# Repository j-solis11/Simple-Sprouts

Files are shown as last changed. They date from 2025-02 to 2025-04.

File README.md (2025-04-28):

# Simple Sprouts - Smart Vertical Farming System



## Quick Start Guide

Simple Sprouts is an autonomous vertical farming system designed for compact urban environments like university campuses and restaurants.
The system integrates smart sensing, adaptive watering and lighting, and AI-based plant health monitoring to enable users to grow plants
Indoors with minimal intervention.

### Project Overview

- **Build Status**: Completed and functional (April 2025)
- **Core Components**: Raspberry Pi 5, Custom PCB, Dual-Tier irrigation, Grow lights, Peltier temperature module, NoIR cameras
- **Key Features**: Three operation modes (Manual, Scheduled, Adaptive), AI plant health monitoring, Web-based user interface
- **Project Team**: Boston University ECE Senior Design Team 26 (Spring 2025)

## Getting Started

### Prerequisites
- Raspberry Pi 5 with microSD card (16 GB+ recommended)
- 24V DC power supply (3A minimum)
- WiFi connection for Firebase access
- React Native Expo for mobile/web interface
- Plant material and growing medium

### Initial Setup
1. Connect the 24V power supply to the system
2. Fill the water tank to the marked level
3. Connect to WiFi and ensure Firebase connectivity
4. Open the web app following the installation instructions in the Software README
5. Initialize plant settings through the app interface
6. Add growing medium and plant material to the containers

### Current Hardware State

- PCB: Fully functional, successfully powering all components through MOSFET switching.
- Power: Stable across all voltage rails (24V input, 12V and 5V regulated buses).
- Irrigation: Pump and solenoid valves reliably operate under manual, scheduled, and adaptive modes.
- Sensing: Soil moisture, temperature/humidity, air quality, and water tank level sensors provide live data.
- Heating: Peltier module + fan assembly actively regulates internal enclosure temperature.
- Enclosure: Sturdy, functional, and water-safe with protective barriers installed.
- Dashboard/Control: Hardware successfully communicates sensor and actuator states via Firebase and web app.

## Critical Lessons Learned

### PCB Design and Assembly
- Footprint Accuracy: Double-check footprints for all parts, especially connectors and larger diodes.
- Part Availability: Use components from suppliers that support automated assembly.
- Clear Labeling: Label all terminal blocks and GPIO pinouts.
- Flyback Protection: Always include flyback diodes across inductive loads, even as a just-in-case.

### Power System
- Oversize Power Supplies: Choose power supplies with 25–50% more headroom.
- Separate High/Low Power Paths: Keep high-current and sensitive signal paths isolated.

### Mechanical Assembly
- Splash Protection: Physical separation between water and electronics is critical.
- Wire Management: Use cable sleeves and zip ties to prevent mechanical stress.

### Testing and Validation
- System-Level Testing: Validate subsystems individually before full integration.
- Sensor Calibration: Calibrate sensors in the actual environment.

### Documentation
- Maintain detailed wiring diagrams from the beginning.

## Known Issues & Gotchas
- Sensor Drift: Soil moisture sensors may drift over time and require recalibration.
- Minor Leakage Possible: Valves tend to leak after overuse. Not used enough usually to reach this stage.

## Recommendations for Future Improvements
- Integrated load sensing for real-time diagnostics.
- Upgrade water tank sensing to more reliable float sensors.
- Add battery backup or solar integration for off-grid use.
- Get better-fitted valve fittings to combat leakage. 

## Current State and Future Development

### Current Implementation
- Fully functional Manual, Scheduled, and Adaptive modes.
- Full web-based control and monitoring.
- NDVI-based plant health monitoring.
- Real-time sensor logging via Firebase.

### Potential Future Development
- Cost-reduction through lower-cost microcontrollers.
- Local AI model deployment to reduce cloud dependency.
- Enhanced environmental control, i.e., humidity and CO2 control
- Expansion to multiple-layered growth systems.
- Integrating multiple users in the same household

### Critical Information for Future Teams

1. **Power Distribution**
   - The system uses a 24V DC supply stepped down to 12V and 5V. Always check voltage levels before connecting new components.
   - The custom PCB has MOSFETs controlling high-current devices. Be cautious when modifying connections to prevent damage.

2. **Irrigation System**
   - Water tube connections at the solenoid valves are pressure-fit and may need occasional reseating.
   - The water pump is rated for 12V but operates efficiently at 9- 15V. The current PCB provides ~12V to the pump.
   - **IMPORTANT**: Always maintain physical separation between water and electronic components.

3. **Software Dependencies**
   - Firebase integration requires proper API keys. See the Software README for setup details.
   - The MoonDream Cloud API has a free tier that may limit daily queries for plant health analysis.
   - React Native Expo dependency versions are critical - see package.json for specific versions.

4. **Sensor Calibration**
   - Soil moisture sensors are factory calibrated but may need recalibration for different soil types.
   - Typical moisture readings: 400-600 (very dry), 600-900 (ideal range), 900+ (overly wet)
   - Temperature sensors have ±1°C tolerance - cross-reference with ambient sensors if precision is required.

5. **Camera Setup**
   - NoIR cameras must be positioned at specific angles for proper plant assessment. Use the 3D-printed mounts.
   - The NDVI analysis uses specific thresholds for plant health determination - see model.py for details.

## Repository Structure

- `/Hardware` - PCB design files, component specifications, and hardware documentation
- `/Software` - Control scripts, web application code, and software implementation details
- `/Assets` - Images, diagrams, and supplementary files
- `/Documentation` - User manual, test plans, and additional project documentation

## Original Team Members

- Jared Solis (jared11@bu.edu)
- Sourav Shib (shib0826@bu.edu)
- Arthur Hua (ahua102@bu.edu)
- Dilhara DeSilva (dilharad@bu.edu)
- Alex Muntean (munteana@bu.edu)

## Conclusion

Simple Sprouts is a fully functioning prototype that brings together embedded systems, smart sensing,
adaptive control, and sustainable agriculture. Moving forward, careful attention to hardware reliability,
documentation quality, and iterative improvements will allow future teams to scale, enhance, and adapt the
platform to even greater applications.

*Boston University Electrical & Computer Engineering*  
*EC 464 Senior Design - Spring 2025*

---

For detailed hardware specifications, see [Hardware README](Hardware/README_HARDWARE.md)  
For software setup and details, see [Software README](Software/readme.md)

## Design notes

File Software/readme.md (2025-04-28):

# Simple Sprouts - Software Documentation

## Software Overview

The Simple Sprouts software stack consists of several interconnected components that enable autonomous plant monitoring, automated environment control, and a user-friendly web interface. The system is primarily built around a Raspberry Pi 5 running Python scripts that interface with sensors and actuators, with data exchanged via Firebase to a React Native Expo web/mobile application.

## Software Architecture and Modules

---

### Mobile App Interface (React Native / Expo)

**Location:** `/React_App`

The mobile app provides a user interface for:
- Viewing real-time sensor data
- Switching   
- Managing manual watering and lighting schedules
- Switching between manual and adaptive modes
- Viewing historical trends in environmental parameters

**Main components:**
- `app/navigation/AppNavigator.js`: 
   - Allows navigation between different screens in the app
   - Configures Tab screen for transitions between Mode Info, Health Info, and Plant Info screens
- `app/services/firebaseServices.tsx`: 
   - Allows communication to Firebase to connect to modules on Raspberry Pi 5
- `app/screens/BasicStatus.tsx`: 
   - Opening screen for the UI 
   - Allows user to see the status of each plant level or reinitialize a new plant
- `app/screens/more_info/ModeInfo.tsx`: 
   - Allows the user to see information pertinent to each mode, i.e. time till next schedule for Scheduling Mode
   - Initializes mode switching
- `app/screens/more_info/HealthInfo.tsx`: 
   - Allows the user to view Plant Health Analysis, which shows LLM results to queries that highlight health
   - Communicates with LLM to allow the user to query the model directly
- `app/screens/more_info/PlantInfo.tsx`: 
   - Displays current and historical sensor information

**Technologies used:**
- React Native Expo 0.22.15
- Expo Go SDK 52

---

### Sensing Script (Python / Raspberry Pi)

**Location:** `/Sensing_Actuation_Code`

   The Sensing_code.py allows Simple Sprouts to continuously monitor soil moisture, air temperature, humidity, CO₂ levels, and water tank levels, uploading this data in real time to Firebase for live user monitoring and automation. The Actuation_code.py uses this sensor data along with flags set from the user app to control the watering system, grow lights, and heater, enabling fully autonomous plant care across Manual, Scheduled, and Adaptive modes. Together, they allow the system to respond to environmental changes, automate daily routines, and minimize manual intervention for indoor vertical farming. 

**Main components:**
- `Sensing_Actuation_Code/sensing_code.py`: 
   - Continuously reads environmental data from AHT20 (temperature/humidity), PCT2075 (temperature), and SGP30 (CO₂/TVOC) sensors over I2C
   - Sample soil moisture and soil temperature from two Adafruit Seesaw soil sensors with different I2C addresses (0x36 and 0x39)
   - Structures all sensor readings into a JSON dictionary with timestamps for organized database updates
   - Uploads the latest sensor data every 2 seconds to the /sensor_readings/latest node in Firebase Realtime Database

- `Sensing_Actuation_Code/Actuation_code.py`: 
   - Manages GPIO-controlled components (lights, valves, pump, heater) on the Raspberry Pi 5 using gpiod and gpiozero libraries
   - Reads control flags and schedules from the Firebase flags_test node to determine component actions and schedules in their respective modes
   - Toggles components on/off based on time-based scheduling or live soil moisture readings
   - Samples an ultrasonic sensor every 5 seconds to measure water tank level and updates the reading to the sensor readings node in Firebase
   - Controls heater based on real-time air temperature relative to a user-defined target temperature

**Technologies used:**
- Libraries Used
  - firebase-admin
  - adafruit-circuitpython-sgp30
  - adafruit-circuitpython-ahtx0
  - adafruit-circuitpython-pct2075
  - adafruit-circuitpython-seesaw
  - board
  - busio
  - json
  - time
  - gpiod
  - gpiozero
- Raspberry Pi 5
- Firebase Realtime Database
- Python3

Notes: 
- Sensing_code.py - Must be ran inside a Python virtual environment (venv) or conda env because Adafruit CircuitPython libraries are installed via pip. I2C must be enabled on the Raspberry Pi. I2C can be enabled using sudo raspi-config.
- Actuation_code.py - Must be ran outside any Python environment because access to /dev/gpiochip0 and GPIO requires special device permissions that the venv typically doesn't have
- You need to have libgpiod installed on the system (sudo apt install gpiod)
- The Firebase credentials file must be correctly set in the absolute path

---
## Model and Camera modules (Python / Raspberry Pi)

**Location:** `/Model_Code`

The camera and model code:
- Takes routine images of the plants
- Processes the images into NDVI images to aid in assessing plant health   
- Sends images up to firebase to be displayed on the web app
- Stores images locally to be passes to model
- Model assess plant health and qualifications to be planted within the planter box
- Model also gives recommendations and schedules on how to take care of plants

**Main components:**
- `Model_Code/Camera_noIR.py`: 
   - Captures plant images and generates NDVI analysis to then send to Firebase
- `Model_Code/image_retrival.py`: 
   - Analyzes plant health and responds to user queries

**Technologies used:**
- NoIR camera
- MoonDream cloud API
- Firebase API
- OpenCv

---

## Flowchart of Modules
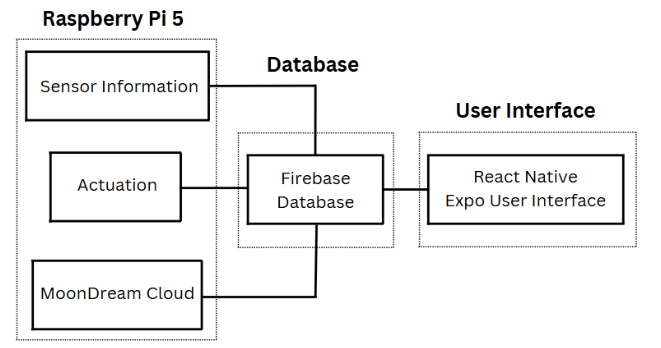
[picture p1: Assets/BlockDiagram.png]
Software Diagram


Here you can see the main flow of data in our logic. Firebase holds all of the hooks into the other modules, which allow the system to work with setting flags and exchanging data. All of the communication is designed with the UI either calling and recieving from the LLM or setting and receiving the sensor/actuation control.

## Software Dependencies and Versions

| Component | Version | Notes |
|---|---|---|
| Python | 3.11.2 | Core language for Raspberry Pi scripts |
| Firebase Admin SDK | 6.2.0 | Python library for Firebase integration |
| PiCamera2 | 0.3.25 | Camera interface library |
| OpenCV | 4.10.0.84 | Image processing library |
| Node.js | 18.16.0 | Required for React Native development |
| React Native | 0.22.15 | Mobile/web application framework |
| Expo Go | 52.0.0 | React Native development platform |
| MoonDream Cloud API | 1.0.0 | AI model API for plant analysis |
| firebase-admin | 2.7.0 | Interface with Firebase Database |
| adafruit-circuitpython-sgp30 | N/A | Air quality sensor interface  |
| adafruit-circuitpython-ahtx0 | 1.0.25 | Humidity sensor interface  |
| adafruit-circuitpython-pct2075 | N/A | Temperature sensor interface |
| adafruit-circuitpython-seesaw | 1.16.5 | Soil sensor interface |
| board | 1.0 | Adafruit Blinka Library |
| gpiod | 2.3.0 | Gpio Control |
| gpiozero | 2.0.2 | Gpio Control |

## Installation and Start up Guide

1. Clone the repository 
```bash
   git clone https://github.com/j-solis11/Simple-Sprouts.git
```
### Model
2. Create venv for camera and model code
```bash
python3 -m venv camera_and_model
source camera_and_model/bin/activate
```
3. Install dependencies for camera and model
```bash
pip install firebase-admin
pip install opencv-python
pip install pyrebase4
pip install requests
sudo apt install -y python3-picamera2
```
4. Activate camera and model code in 2 seperate terminals
```bash
python Camera_noIr.py
python image_retrival.py
```

### React App
2. Navigate to /Software/React_App/app/services/firebaseService.ts to put in Firebase API Key.

3. Open Command Prompt and navigate to /Software/React_App. 

4. Install Expo
```bash
npm install expo
```

5. Start app
```bash
npx expo start --tunnel
```
### Sensing and Actuation Code
2. Create the environment for the sensing script
```bash
python3 -m venv sensing_env
source sensing_env/bin/activate
```
3. Install dependencies for the sensing system
```bash
pip install firebase-admin adafruit-circuitpython-sgp30 adafruit-circuitpython-ahtx0 adafruit-circuitpython-pct2075 adafruit-circuitpython-seesaw adafruit-blinka
```
4. Enable I2C
```bash
sudo raspi-config
sudo reboot
```
5. Install dependencies for the actuation script
```bash
sudo apt install python3-pip python3-gpiozero libgpiod-dev python3-libgpiod
sudo pip3 install firebase-admin
```
6. Activate the environment for the sensing script
```bash
source sensing_env/bin/activate
python Sensing_code.py
```
7. Run the actuation script (In another terminal)
```bash
python3 Actuation_code.py
```

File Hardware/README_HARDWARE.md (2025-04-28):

# Simple Sprouts Hardware Report

## Overview

Simple Sprouts is an autonomous vertical farming system built around a custom-designed PCB, a Raspberry Pi 5
controller, and integrated environmental sensing and actuation. The system uses sensor feedback to manage irrigation, lighting, and temperature across a two-level enclosure. All design files, CAD models, schematics, and supporting documentation are included in the GitHub repository to allow future teams full access for reproduction or improvement.

This document serves as the complete hardware report, detailing schematics, PCB/CAD designs, Bill of Materials (BOM), datasheet references, power specifications, and physical system documentation.

## 1. Schematics, PCB, and CAD Diagrams

### Schematic Files:
- KiCad 8.0 project files (.sch) are located in /Hardware/KiCAD/Simple_Sprouts_PCB
- PDF exports of full schematic diagrams are provided for easy reference.

### PCB Layout Files:
- Full KiCad PCB layout files (.kicad_pcb) included.
- Gerber files for PCB fabrication provided in /Hardware/KiCAD/Simple_Sprouts_PCB/production
- PCB designed as a two-layer board with:
  - 2mm traces for high-current paths
  - 0.25mm traces for logic-level signals
  - Separate 12V and Ground planes
- 3D visualizations of PCB assembly available in /Hardware/Photos

### CAD Drawings:
- Mechanical design built primarily from plywood and 1/8" acrylic panels.
- Simple 2D CAD sketches (PDF) and final enclosure photographs provided in /Hardware/Photos

## 2. Vendor Information and Bill of Materials (BOM)

### PCB and Electrical Components:
- PCB Fabrication & Assembly: JLCPCB (www.jlcpcb.com)
- MOSFETs: Texas Instruments CSD18532Q5B
- Terminal Blocks: Phoenix Contact 1751248 (C89122)
- Flyback Diodes: SS510 Schottky Diodes (Microdiode)
- Soil Moisture Sensors: Capacitive 3.0–5.5V sensors (generic vendors)
- Temperature/Humidity Sensor: DHT22 (Adafruit)
- Air Quality Sensor: MQ-135 (Adafruit)
- Ultrasonic Distance Sensor: HC-SR04 (generic)
- Water Pump: 12V diaphragm pump (SparkFun equivalent)
- Solenoid Valves: 12V normally closed (Amazon)
- Grow Lights: 12V white LED strips
- Heating Unit: 12V Peltier Module + fan combo
- DC-DC Converters: 24V-12V and 24V-5V buck converters (Pololu)
- Power Supply: MeanWell GST60A24-P1J (24V, 2.5A output)

### Mechanical Components:
- 1/8" Acrylic Panels (Amazon)
- Plywood Sheets (Home Depot)
- Push-to-connect irrigation fittings
- 1/4" Tubing (Home Depot)
- M3 Screws and Nylon Standoffs

### Complete BOM:
- Located in /Hardware/Datasheets/SimpleSprouts_BOM.xlsx
- Includes quantity, part number, description, supplier link.

## 3. References to Datasheets and Design Resources
All are available in /Hardware/Datasheets
- MOSFET Datasheet: CSD18532Q5B
- Flyback Diode Datasheet: SS510 Schottky Diode Datasheet
- Phoenix Terminal Block Datasheet: 1751248 Datasheet
- Soil Moisture Sensor: Capacitive Sensor General Guide
- DHT22 Datasheet: DHT22 Humidity and Temperature Sensor
- Peltier Module Datasheet: TEC1-12706 (available in /Hardware/Datasheets/HardwareSensors/heater.pdf)
- MQ-135 Air Quality Sensor Datasheet: (available in /Hardware/Datasheets/HardwareSensors/air quality sensor.pdf)

## 4. Power Requirements

### Primary Power Source:
- 24V DC regulated supply rated at 3A (MeanWell GST60A24)

### Voltage Rails:
- 24V Primary Input Rail
- 12V Step-down Rail (via DC-DC converter) for:
  - Water Pump
  - Solenoid Valves
  - Peltier Heating Module
- 5V Step-down Rail (via DC-DC converter) for:
  - Raspberry Pi 5
  - LED Grow Lights
  - All environmental sensors

### Typical System Power Load:
- Raspberry Pi 5: ~1.5A @ 5V
- Water Pump: ~0.8A @ 12V (peak)
- Solenoid Valves: ~0.25A each @ 12V
- LED Grow Lights: ~0.5A total @ 12V
- Peltier Module + Fan: ~2A @ 12V (peak)

### Important Power Notes:
- Confirm 5V and 12V outputs before wiring critical loads.
- Avoid running pump and Peltier at full load simultaneously for long periods unless supply margin is verified.

## Power Requirements

| **Component** | **Voltage Requirement** | **Current Draw** | **Power Source** |
|:---|:---|:---|:---|
| Raspberry Pi 5 | 5V | 3A | 24-5V USB-C Converter |
| NoIR Camera Module (x2) | 5V | 125 mA (each) | 24-5V Converter |
| Water Cooled Water Pump | 12V | 300 mA | 24-12V Converter |
| Peltier Heating Module | 12V | 4A | 24-12V Converter |
| Solenoid Valve (x2) | 12V | 250 mA (each) | 24-12V Converter |
| Grow Light LED Strips (x2) | 5V | 3A (each) | 24-5V Converter |
| Soil Moisture Sensors (x2) | 5V | 10 mA (each) | 24-5V Converter |
| Temperature Sensor | 5V | 2.5 mA | 24-5V Converter |
| Humidity Sensor | 5V | 2.5 mA | 24-5V Converter |
| Air Quality Sensor | 5V | 2.5 mA | 24-5V Converter |
| Ultrasonic Distance Sensor | 5V | 15 mA | 24-5V Converter |

*Table: Summary of Power Requirements*

## 5. System Photographs and Assembly Documentation

Photographs have been captured and placed in /Hardware/Photos showing:
- PCB Top View (fully populated)
- PCB Side View (showing component height and header stacking)
- Full System Inside View (component wall and irrigation)
- Close-up of Irrigation System and Water Tank
- Cable Management and Tubing Routing
- Finished Enclosure with Plants Installed

### Notes on System Assembly:
- Maintain splash protection by securing acrylic barrier.
- Secure tubing with clamps and hot glue as needed.
- Run 24V input wiring separately from sensor wiring to avoid noise.
- Keep DC-DC converters in ventilated spaces inside the frame.

## 6. Additional Resources
- KiCad Project Backup (/Hardware/KiCAD/Simple_Sprouts_PCB/Simple_Sprouts_PCB-backups)
- Web links to component datasheets.

## Conclusion

The Simple Sprouts hardware platform is a fully operational and scalable embedded agricultural system.
With modular design choices, strong documentation, and open project files, it is positioned for
straightforward maintenance, upgrades, and future research use. By following careful engineering
practices, future teams can continue to enhance its sustainability, expandability, and
performance in smart agriculture applications.

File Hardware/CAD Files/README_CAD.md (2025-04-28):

This folder contains all of the CAD files we created to visualize our Simple Sprouts
project. Please note that these files are very outdated and were never kept up to date
because we felt that this was beyond our scope for the project and what we wanted to achieve.
We only wanted a simple frame that got the job done, we did not need to manufacture our own
custom parts with tolerances. Therefore, this folder serves as a visualization of the early stages
of Simple Sprouts, highlighting why we chose to go the way we did.

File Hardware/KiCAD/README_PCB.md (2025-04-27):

This is the PCB folder.
All necessary KiCAD files can be found within this folder.
In the "production" folder is the folder
used to export the schematics to JLC PCB for fabrication.

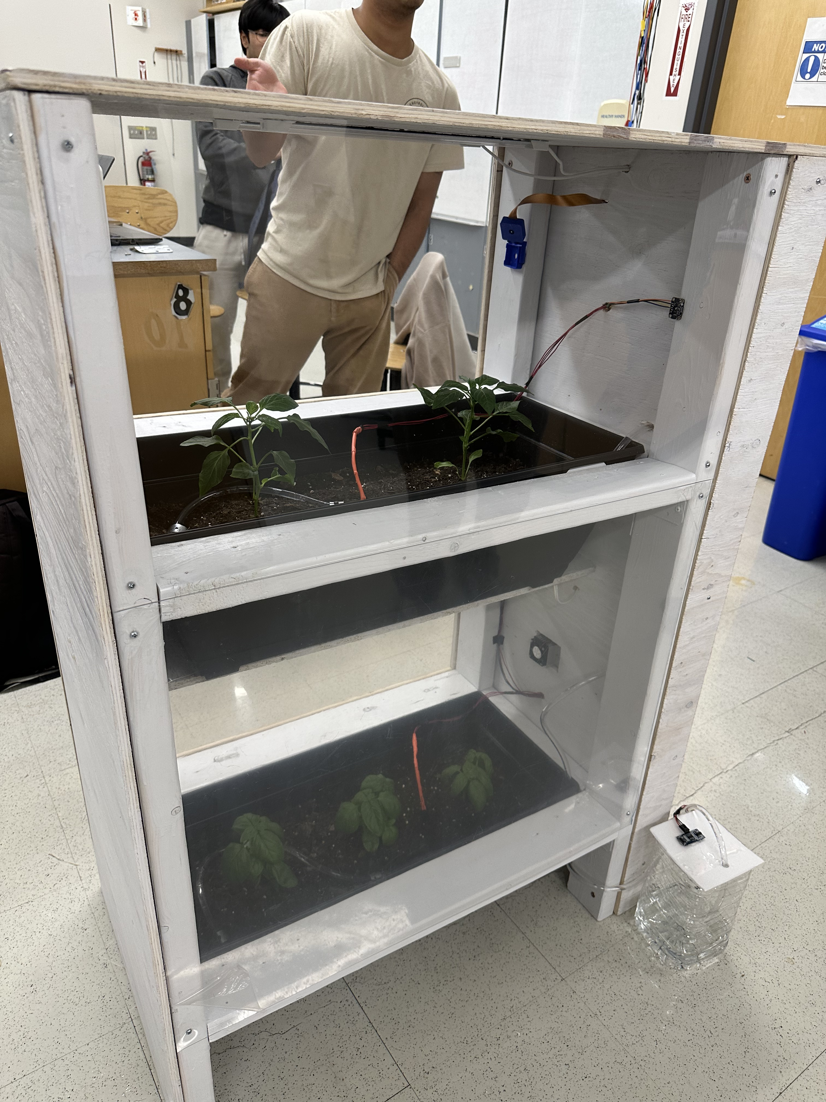
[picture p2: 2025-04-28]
Hardware/Photos/acyrlic.JPEG

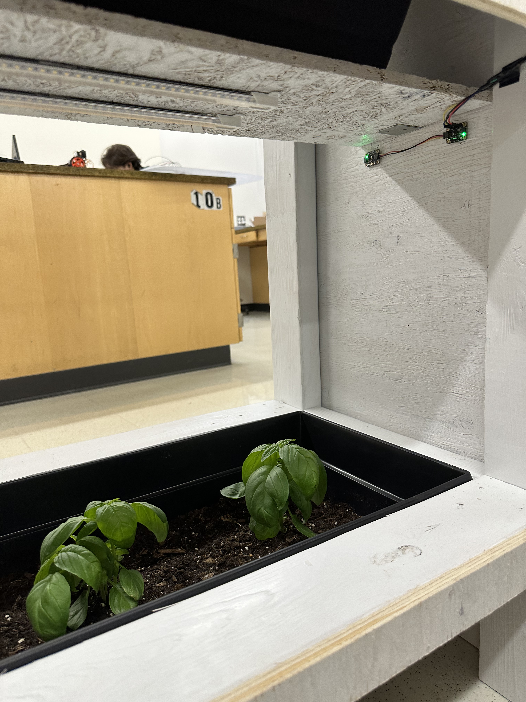
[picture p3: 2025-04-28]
Hardware/Photos/temp humidity sensors.JPEG

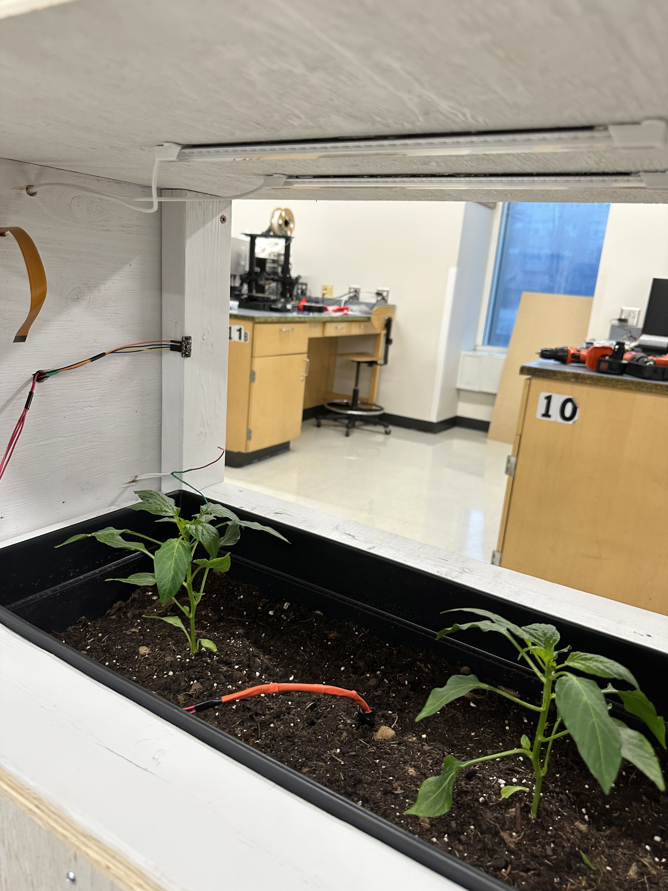
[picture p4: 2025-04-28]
Hardware/Photos/air quality sensor.JPEG

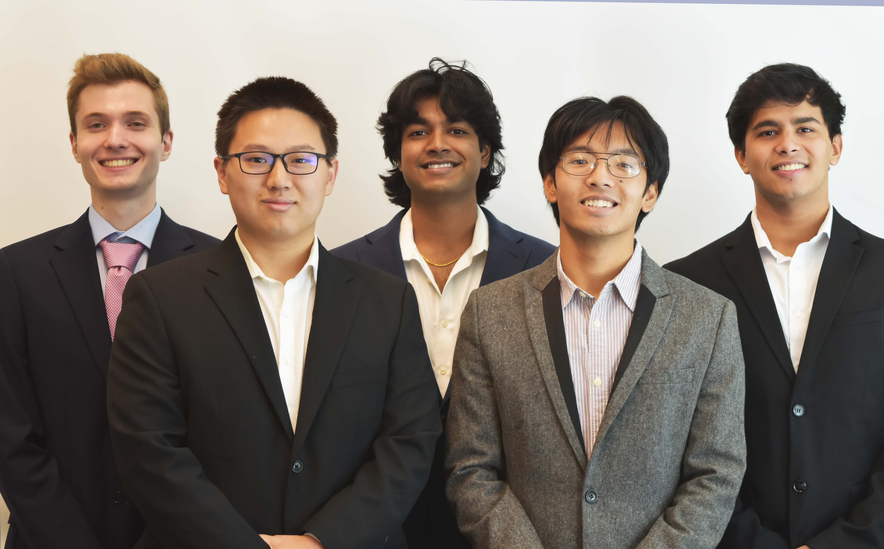
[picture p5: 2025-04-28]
Hardware/Photos/team photo.jpg

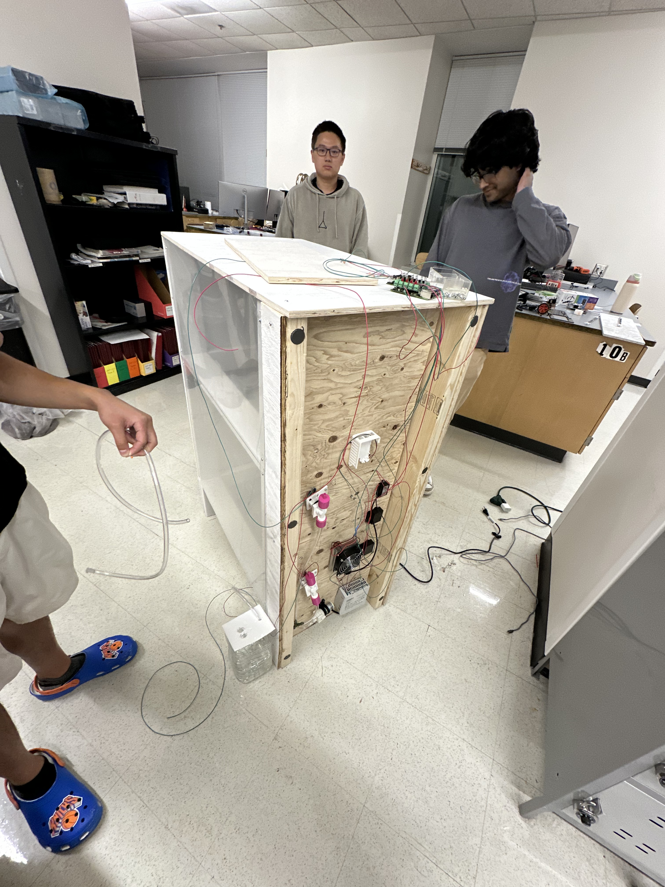
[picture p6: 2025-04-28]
Hardware/Photos/us working!.JPEG

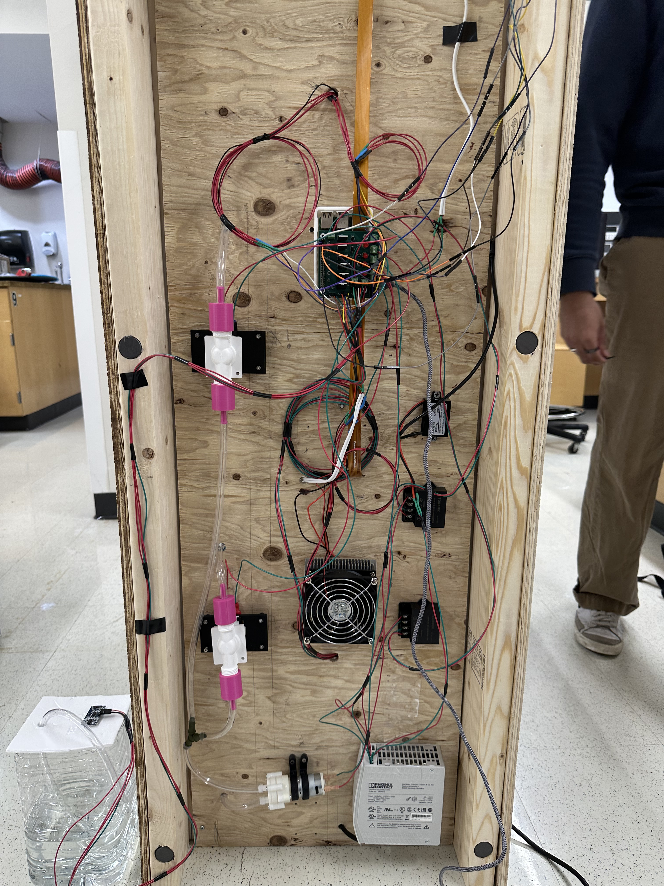
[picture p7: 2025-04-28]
Hardware/Photos/hardware panel.JPEG

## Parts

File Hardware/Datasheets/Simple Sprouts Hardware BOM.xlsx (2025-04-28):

Senior Design Expense Tracking
 | Vendor | Item(s) Purchased In Order | Total Cost
1) | Home depot | Black plant box | $24.98
2) | Home depot | Potting Mix | $9.97 | Total: | $740.52
3) | Home depot | Mini Marble Chips | $6.78
4) | Home depot | Clear Silicone Loctite | $6.28
5) | Home depot | PTFE tape | $0.98
6) | Home depot | Plastic lamp holder | $4.66
7) | Home depot | Pepper plants | $5.98
8) | Adafruit | Sensors and others | $92.55
9) | Amazon | jst cable | $8.00
10) | microcenter | Raspiberry pi 5 | $85.00
11) | amazon | noIR camera module | $29.99
12) | Adafruit | 2 x Plastic Water Solenoid Valve | $21.36
13) | Home Depot | zmax steel framing angle 1-1/2'' | $9.00
14) | Home Depot | zmax steel framing angle 3'' | $18.12
15) | Home Depot | plastic planter box | $6.32
16) | Home Depot | white wood planks | $23.10
17) | Target | Plant Germinating cups | $10.61
18) | Home Depot | Plant food | $11.97
19) | Home depot | Garden Soil | $4.57
20) | Newark | SCHOTTKY RECTIFIER, 5A, 100V | $11.80
21) | Mouser Electronics | Mosfet | $18.80
22) | Amazon | USB C Step Down Converter | $9.99
23) | Amazon | 120W Step Down Buck Converter | $9.39
24) | Amazon | Ribbon strip camera converter | $7.97
25) | Amazon | Grow light led strips | $27.98
26) | Amazon | New tube | $8.00
27) | Amazon | New pump | $10.00
28) | Amazon | DC 12v-24C step down | $11.00
29) | Digikey | PCB parts | $36.08
30) | Digikey | PCB (manufacturing) | $21.34
31) | Amazon | Acrylic | $32.29
32) | Amazon | noIR camera module | $32.99
33) | Amazon | Flexible camera cable | $7.97
34) | Home depot | zinc woodscrew 10@1.38 | $13.80
35) | Home depot | White spray paint 2@5.98 | $11.96
36) | Home depot | 1-1/2'' steel framing angle 10@0.90 | $9.00
37) | Home depot | plywood | $24.80
38) | Home depot | White spray paint 6@5.98 | $35.88
39) | Home depot | Steel framing angle 3'' 6@1.51 | $9.63
40) | Home depot | Steel framing angle 3'' 6@1.51 | $9.63

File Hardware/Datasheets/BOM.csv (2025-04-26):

Designator | Footprint | Quantity | Value | LCSC Part #
12V IN, 5V IN | TerminalBlock_Phoenix_PT-1,5-2-3.5-H_1x02_P3.50mm_Horizontal | 2 | Conn_01x02
D1, D2, D3, D4 | LED_D5.0mm | 4 | LED
D5, D6, D7, D8 | D_SMA | 4 | SS510
GROW1, GROW2 | TerminalBlock_Phoenix_PT-1,5-2-3.5-H_1x02_P3.50mm_Horizontal | 2 | ~
HEATER | TerminalBlock_Phoenix_PT-1,5-2-3.5-H_1x02_P3.50mm_Horizontal | 1 | R1
J1 | RPI Correct | 1 | Raspberry_Pi_5
J3, J4 | PinHeader_1x04_P2.54mm_Vertical | 2 | Soil Sensor
J6 | PinHeader_1x04_P2.54mm_Vertical | 1 | Temperature Sensor
J7 | PinHeader_1x04_P2.54mm_Vertical | 1 | Air Quality Sensor
J8 | PinHeader_1x04_P2.54mm_Vertical | 1 | Humidity Sensor
J9 | PinHeader_1x04_P2.54mm_Vertical | 1 | HC-SR04
Q1, Q2, Q3, Q4, Q5, Q6 | TO-220-3_Vertical | 6 | IRLB8721PbF
R10, R11, R12, R13, R14 | 1206 | 5 | 1kΩ
R15 | 1206 | 1 | 2kΩ
R2, R3 | 1206 | 2 | 4.7kΩ
R4, R5, R6, R7, R8, R9 | 1206 | 6 | 10kΩ
VALVE1, VALVE2 | TerminalBlock_Phoenix_PT-1,5-2-3.5-H_1x02_P3.50mm_Horizontal | 2 | L
WATER PUMP | TerminalBlock_Phoenix_PT-1,5-2-3.5-H_1x02_P3.50mm_Horizontal | 1 | 12V

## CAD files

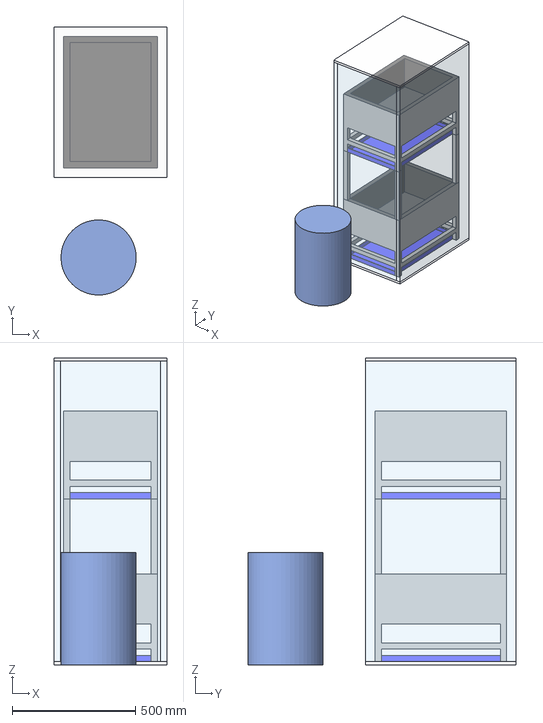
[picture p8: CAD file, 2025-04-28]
Hardware/CAD Files/Assembly 1.step
457.2 x 1087.4 x 1245.2 mm

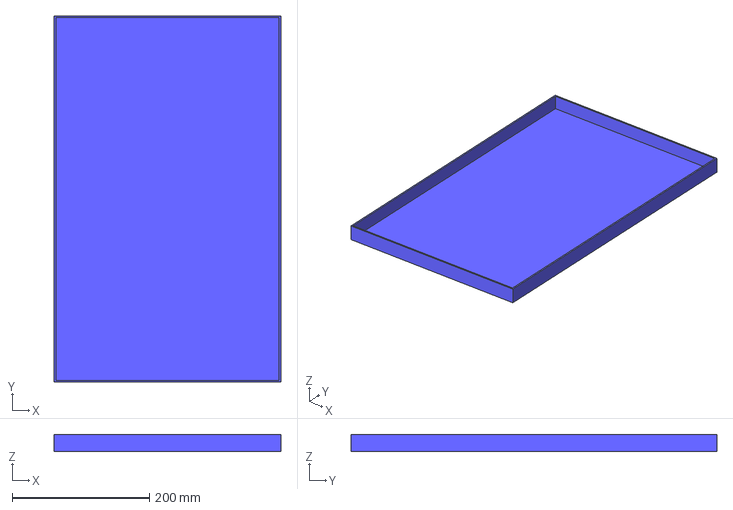
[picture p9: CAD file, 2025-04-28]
Hardware/CAD Files/Drip Tray.step
330.2 x 533.4 x 25.4 mm

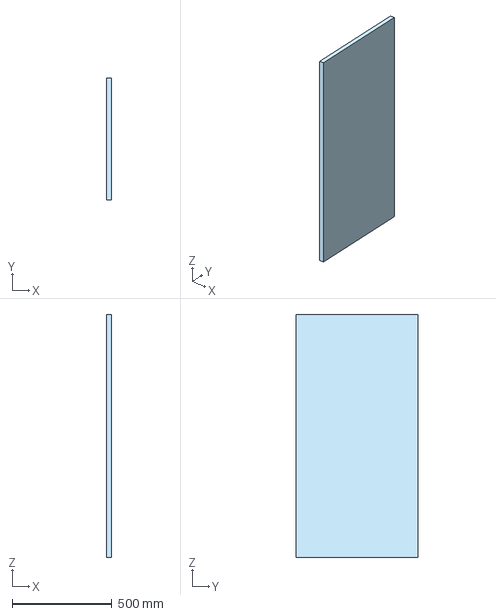
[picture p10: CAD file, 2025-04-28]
Hardware/CAD Files/Side Panels.step
25.4 x 609.6 x 1219.2 mm

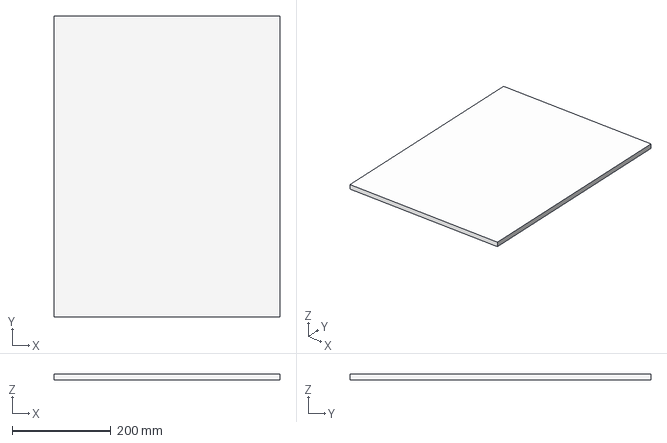
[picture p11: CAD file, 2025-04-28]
Hardware/CAD Files/Floor.step
457.2 x 609.6 x 12.7 mm

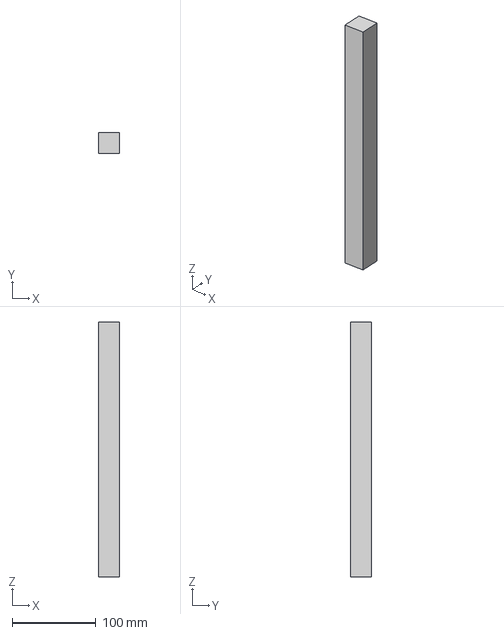
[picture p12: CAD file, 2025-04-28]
Hardware/CAD Files/Pillar Support.step
25.4 x 25.4 x 304.8 mm

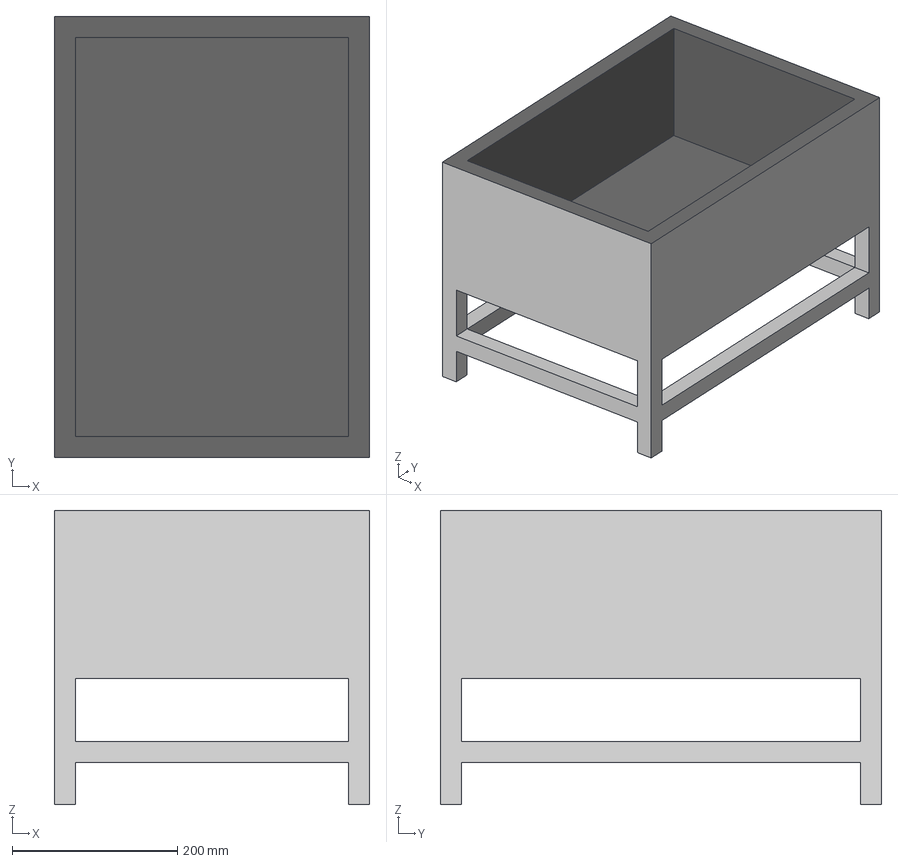
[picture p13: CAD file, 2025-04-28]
Hardware/CAD Files/Planter.step
381.0 x 533.4 x 355.6 mm

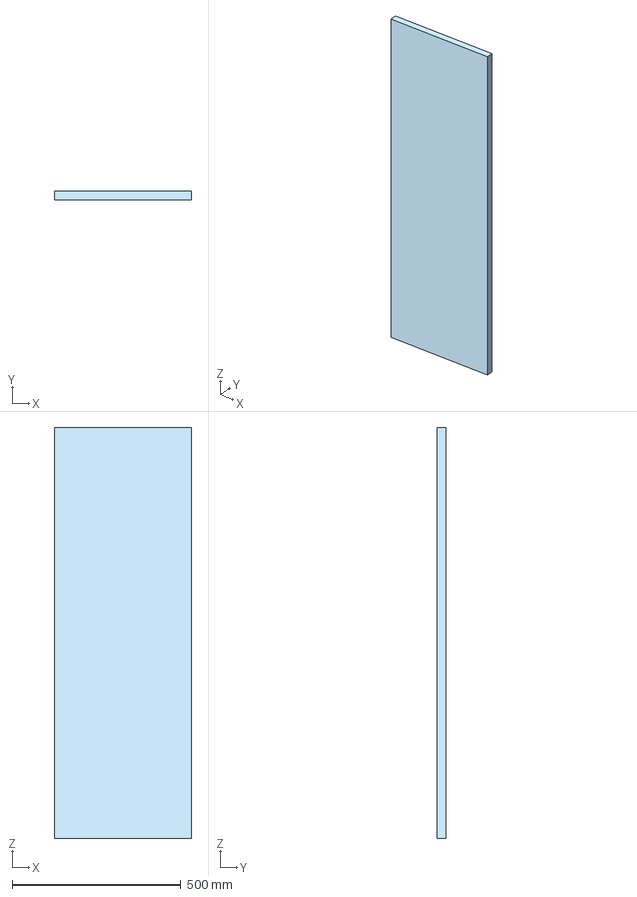
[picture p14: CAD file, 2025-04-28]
Hardware/CAD Files/Front & Back Panel.step
406.4 x 25.4 x 1219.2 mm

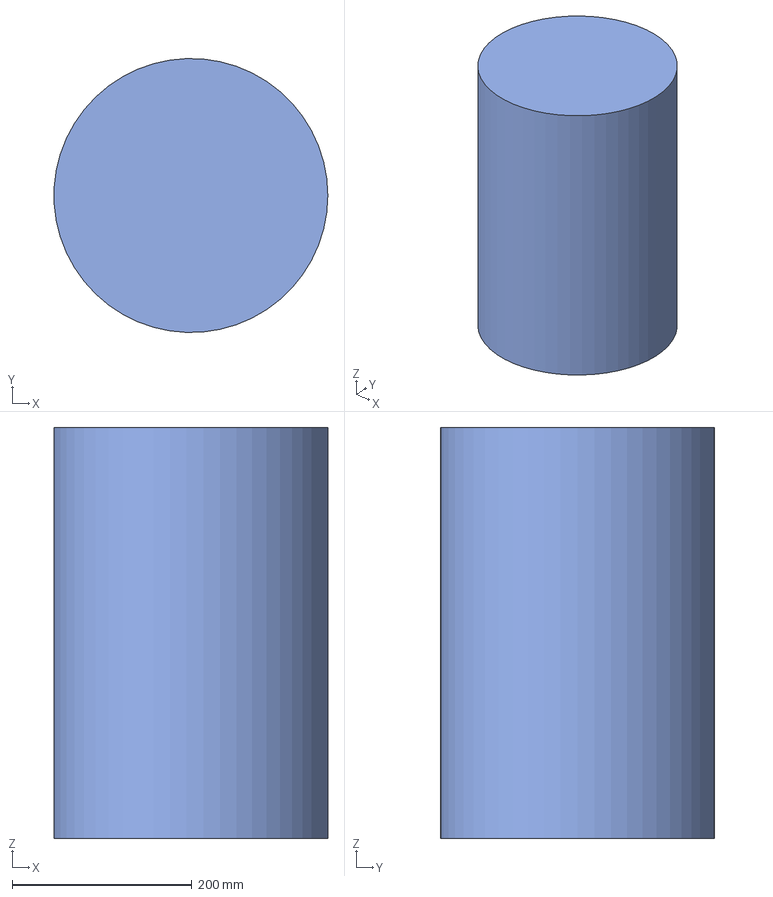
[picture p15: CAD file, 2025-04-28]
Hardware/CAD Files/Water Tank.step
304.5 x 304.7 x 457.2 mm

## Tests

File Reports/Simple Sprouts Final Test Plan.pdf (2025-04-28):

## Boston University Electrical & Computer Engineering

EC 464 Senior Design Project

## Final Product Testing Plan

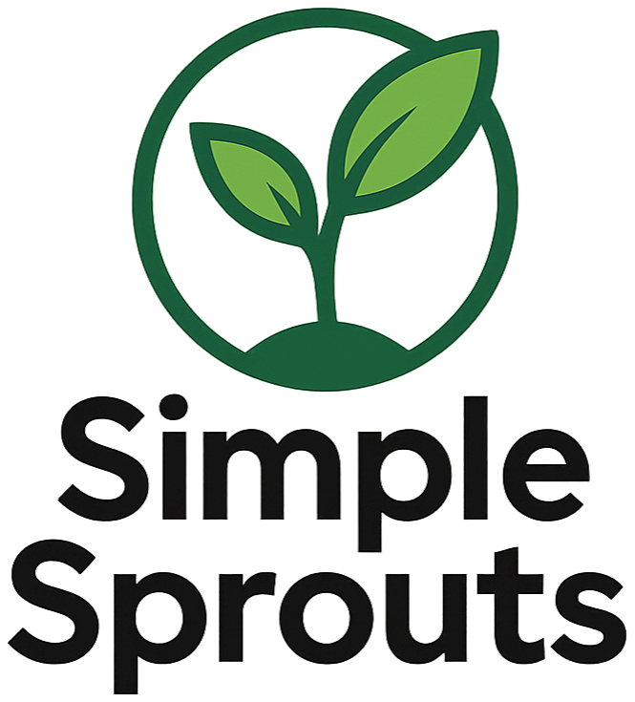
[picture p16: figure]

by
Team 26

Dilhara DeSilva dilharad@bu.edu Arthur Hua ahua102@bu.edu
Alex Muntean munteana@bu.edu Jared Solis jared11@bu.edu Sourav Shib shib0826@bu.edu

Required Materials

Hardware:
- Raspberry Pi 5
- 24V DC Power Supply
- 24V to 12V DC-DC Converter
- 24V to 5V DC-DC Converter
- 12V to 5V DC-USB-C Output Converter
- Raspberry NoIR Camera Module (2)
- 12V Water Cooled Water Pump Air Diaphragm Pump
- 12V Peltier Heating Module with Heat Sink and Fan
- 12V Solenoid Valves (2)
- Grow Light LED Strips (2)
- Soil Moisture Sensors (2)
- Temperature Sensor
- Humidity Sensor
- Air Quality Sensor
- Custom Fully Assembled PCB

Software:
- Python Scripts (Raspberry Pi GPIO control w/ scheduling logic, sensor handling)
- Capturing Photos & Object Recognition (OpenCV, TensorFlow for plant analysis)
- React Native Expo (Mobile/Web UI for monitoring and control)
- Node.js Web Server (Data visualization and API communication)
- Adafruit Sensor Libraries (for data collection from environmental sensors)
- Firebase (Cloud-based data storage and real-time updates for system communication)

Modes of Operation:

1. Manual Mode: User manually controls watering and lighting via the web app.
2. Schedule Mode: User sets their own or one of the predefined schedules for watering and lighting cycles.

### 3. Adaptive Mode: System responds dynamically based on sensor input and camera

feedback.

Set Up

The system consists of the following components:
- Raspberry Pi 5: Manages all sensor readings (soil moisture, temperature, humidity, air quality, water lever), controls the solenoid valves, water pump, and grow lights via GPIO-PCB control (using MOSFETs for on/off function), and processes infrared images for plant health monitoring. Handles requests with vision model for plant health
- Power Distribution: Uses a 24V DC power supply with three DC-DC converters (12V for the water pump, solenoids, and heater, 5V for the grow lights, and 5V USB-C for the Raspberry Pi).
- Web App: Displays real-time sensor data, images captured by the camera, and AI-based plant health assessments. Allows users to control and monitor the system remotely.
- Peltier Module: Maintains internal temperature within the optimal range for plant growth.
- Sweet Basil & Hot Banana Peppers: Test crops; the peppers were selected for their bright color to enhance camera-based plant health detection. Basil and other leafy greens like lettuce and spinach account for over 57% of crops grown in vertical farming systems.

All systems are now built on the custom PCB, replacing the individual breadboard circuits.

Pre-testing Setup Procedure

1. Connect all sensors (soil moisture, temperature, humidity, air quality, water level) to the Raspberry Pi and verify communication with RPI and Firebase
2. Ensure the Raspberry Pi is connected to the NoIR Cameras and can capture infrared images using Python. Ensure the Pi can process images using OpenCV and NVDI
3. Verify optimal water levels in storage manually.
4. Set up the DC power supply to provide 12V power for the water circuit and 5V for the Raspberry Pi and grow lights.
5. Ensure proper control of the water pump, solenoid valves, LED strips, and heater through the MOSFETs.
6. Upload and run the control code on the Raspberry Pi for automation and monitoring. Ensure timing for schedules is accurate
7. Run a test script to ensure image capture and AI-based plant monitoring functions correctly.
8. *Continuity Testing
a. Inspect PCB solder joints (MOSFETs, diodes) and water pump health (due to manufacturer’s notice).

Workflow Testing

1. Grow Light Activation
- Triggered via Raspberry Pi GPIO control through Schedule, Manual, or Adaptive mode.
2. Watering System
- Soil moisture sensor triggers water pump via Raspberry Pi in adaptive mode. In scheduling mode, the water pump and valves are triggered using timing schedules.
- Water pump and respective level is manually activated via Pi logic through the app.
- Water flows from the water pump to the Y-Connector and then through its respective solenoid valve.
i. Confirmed visually and through moisture sensor readings.
3. Camera & AI Processing
- Camera captures plant images with a NoIR and processes it to create an NDVI image to make assessing plant health easier
- Web app displays sensor data, IR plant images, and AI-based assessments.

### 4. Sensor Integration

- All environmental sensors upload real-time data to Firebase.
- Ultrasonic sensor detects and reports low water levels.
- Sensor script stores historical sensor data every twelve hours

### 5. Heater Module Test

- Activates automatically via Raspberry Pi Logic when enclosure temperature falls below 75℉ (± 5℉).
i. *Note For purposes of manual testing, this threshold can be set to a lower value in the code.

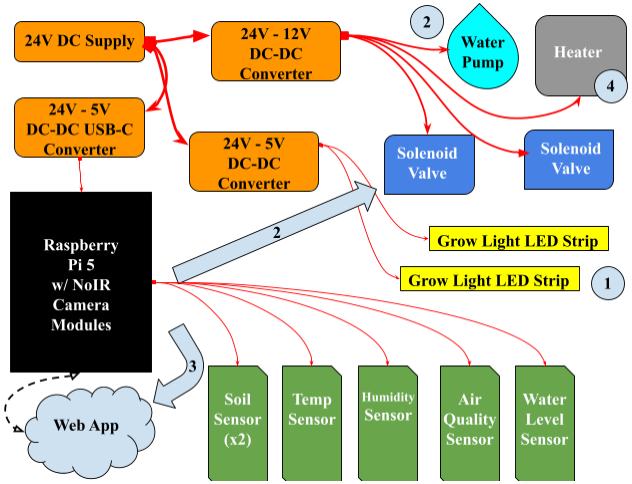
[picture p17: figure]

Figure 1: Illustration of Setup and Process Flow

Testing Procedure

Grow Light Test
- Confirm that the Raspberry Pi can toggle grow lights through both manual and scheduled modes via the web app.
- Ensure activation is time-aligned with defined schedule parameters.

Watering System & Soil Moisture Test
- Measure real-time soil moisture data from both sensors.
- Trigger watering cycle when soil moisture falls below a set threshold.
- Confirm pump activation and water flow through solenoid valves and Y-connector.
- Validate that the pump stops automatically once the desired moisture level is reached.
- Manually toggle watering ON/OFF from the app and verify the response.

Camera & AI Image Processing Test
- Capture images of Sweet Basil and Hot Banana Pepper plants using NoIR cameras.
- Uses MoonDream cloud API to evaluate plant health and get advice based on the images taken
- Confirm that captured images are correctly processed and health classifications are sent to the web dashboard through firebase.
Environmental Sensor Integration Test
- Collect real-time data from all sensors:
- Soil Moisture
- Temperature
- Humidity
- Air Quality
- Ultrasonic Distance Sensor (for water reservoir level)
- Ensure Raspberry Pi receives accurate readings and pushes updates to Firebase.
- Confirm data is correctly parsed and displayed on the web app interface with minimal lag or data loss.

Heating & Cooling System Test
- Test GPIO control of the heater module.
- Monitor temperature changes through the environment sensor before and after activation.
- Ensure thermal regulation maintains the desired enclosure range.

Measurable Criteria

Test Case | Expected Outcome | Pass/Fail
Grow Light Control A. Scheduled mode B. Manual mode C. Adaptive mode | Lights turn on/off as scheduled or in manual mode. Lights follow schedule set by model in adaptive mode
Water Pump Activation A. Scheduled mode B. Manual mode ————————— C. Adaptive mode | Water pump & its respective solenoid valve turns on/off as scheduled or in manual mode ———————————— Water pump & its respective solenoid valve turns on/off when the soil moisture sensor detects dry soil
Image Capture | Successful infrared image

| capture
AI Plant Assessment | Accurate AI evaluation of plant health
Sensor Data Display | Real-time data from temp/humidity/moisture/air/ul trasonic sensors is uploaded to web app and Firebase
Heating Functionality | Heating on/off toggles via Pi, confirmed by temperature changes

Additional Observations

- LED strips powered via PCB are brighter and more stable than in the breadboard prototype.
- System wiring is fully enclosed and neatly mounted.
- It is much more convenient with the PCB due to its terminal blocks for the systems’ wiring and the 4-pin connectors for the sensors’ wiring.
- Final hardware is now installed into a fully enclosed, multi-layer wooden frame with acrylic facing, allowing full view of the crops front and back.
- Ultrasonic sensor provides additional robustness by alerting users when the water tank needs refilling.
- Replacing SRDs improved overall power reliability and reduced noise during operation.

Future Steps (Pre-ECE Day)

- Make a permanent mounted enclosure for the water level sensor on the water tank.
- Re-apply paint to improve visual appeal.
- Laser engrave the team logo and name onto the side of the frame.
- Clean up wiring.
- Keep the system running to take care of our crops for ECE Day.

Conclusion

The Simple Sprouts project represents a fully integrated and functional automated plant care system, combining sensor feedback, intelligent control, and user interaction through a custom web interface. With the successful completion of the PCB build, full system soldering, and enclosure construction, the prototype now supports stable and efficient operation. New additions like the ultrasonic distance sensor and Peltier heating module enhance environmental control, while the grow lights, soil moisture sensors, and solenoid-pump irrigation system operate reliably through both scheduled and manual modes.
The inclusion of Sweet Basil and Hot Banana Peppers not only serves functional irrigation testing but also strengthens our AI model’s performance in real-time plant health monitoring through IR imaging. The bright coloration of the peppers improves contrast and detection accuracy for camera-based analysis. Cloud synchronization via Firebase enables seamless data flow between the Raspberry Pi and the web dashboard, maintaining live system transparency and control.
By completing the final hardware implementation, integrating all power, irrigation, and sensor systems into a unified architecture, Simple Sprouts is now positioned as a robust, scalable smart agriculture solution. Future directions will explore enhancing adaptive logic, expanding AI-based care recommendations, and refining mechanical features for long-term deployment.

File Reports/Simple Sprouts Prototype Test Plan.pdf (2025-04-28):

## Boston University Electrical & Computer Engineering

EC 463 Senior Design Project

## First Prototype Testing Plan

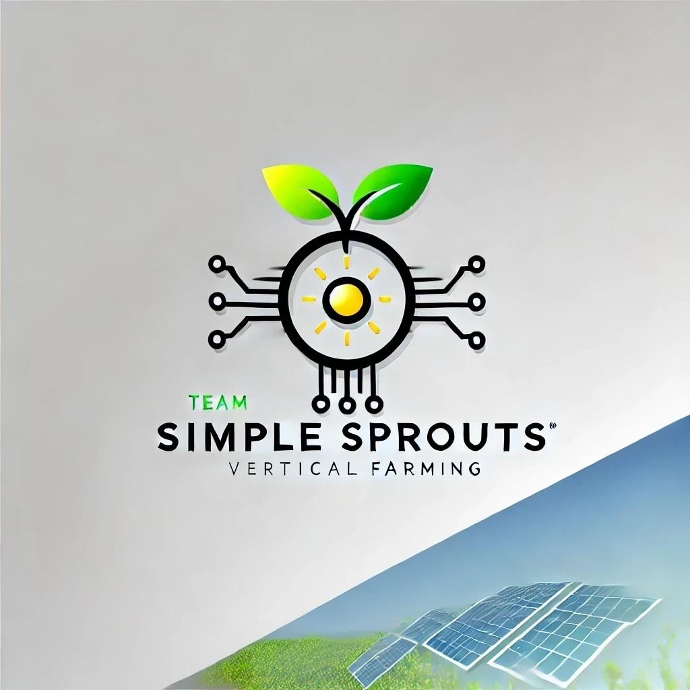
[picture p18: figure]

by
Team 26

Dilhara DeSilva dilharad@bu.edu Arthur Hua ahua102@bu.edu
Alex Muntean munteana@bu.edu Jared Solis jared11@bu.edu Sourav Shib shib0826@bu.edu

Required Materials:

Hardware:
- Raspberry Pi 1 Model B
- ESP32 Microcontroller
- 12V DC Variable Power Supply
- Camera Module (Logi Webcam HD 1080p)
- 12V Peristaltic Water Pump
- Adafruit Soil Moisture Sensors (2)
- SRD (2)
- 9V Battery
- 11W Grow Light
- Flywheel Diode
- Resistor
- Inverter

Software:
- Python 3 Scripts
- Capturing photos
- Object recognition
- Arduino IDE
- React Native Expo
- Arduino IDE for ESP32
- Python scripts for image recognition (OpenCV, TensorFlow)
- Web server (Node.js) for data visualization
- Sensor handling libraries (Adafruit libraries for sensors)

Set Up:

The system consists of the following components:

1. ESP32: Manages sensor readings (soil moisture, light, temperature, humidity) and controls the water pump and grow lights using step recovery diodes.
2. Raspberry Pi: Handles image capture using the webcam and processes the images using a trained model for ripeness detection.
3. Power Supply: Uses a DC variable power supply for consistent voltage output due to unreliable battery performance in previous tests.
4. Web App: Displays real-time sensor data and images captured by the camera.

Pre-testing Setup Procedure:

1. Connect all sensors (soil moisture, light, temperature/humidity) to the ESP32 and verify communication via I2C.
2. Ensure the Raspberry Pi is connected to the camera and can capture images using Python.
3. Verify optimal water levels in water storage.
4. Set up the DC power supply to provide 12V power for the water pump and grow LEDs.
5. Upload the control code to the ESP32 using Arduino IDE.
6. Run a test script on the Raspberry Pi to ensure image capture and basic object detection are functioning correctly.

Workflow Testing:
1. Light scheduled to turn on → ESP32 triggers grow light activation.
2. Soil moisture sensor detects dry soil → ESP32 triggers water pump activation.
a. Water pump scheduled to turn on → ESP32 triggers water pump activation.
3. Camera captures plant image → Raspberry Pi processes ripeness percentage through camera model → Web app displays all sensor data, the image, and ripeness status.

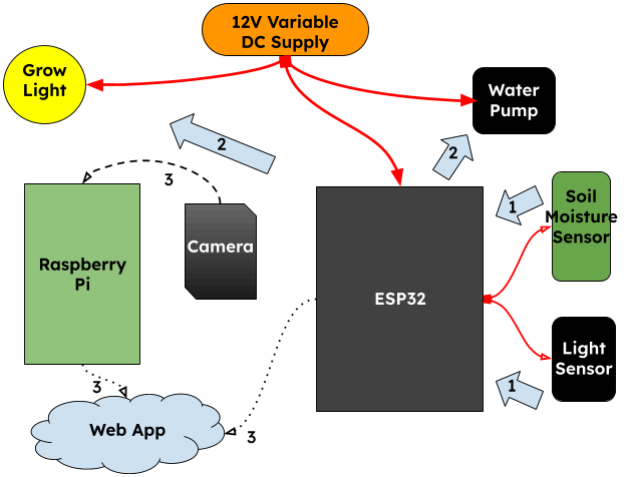
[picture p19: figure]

Figure 1: Illustration of Setup and Process Flow

Testing Procedure:

1. Lighting Test:
- Place the planter box under the grow lights.
- Use the light sensors to monitor ambient light levels measured in lux.
- Verify that the ESP32 adjusts the grow lights based on the sensor readings using the MOSFET control circuit.
2. Water Pump Test:
- Measure soil moisture levels using capacitive touch sensors. This system provides precise readings on a scale from approximately 200 (very dry) to 2000 (very wet), enabling accurate monitoring of soil hydration.
- Ensure the water pump operates correctly using the MOSFET control and stops once the desired moisture level is reached.
- The water pump operates from an ON/OFF command.
3. Camera and Image Processing Test:
- Set up the Raspberry Pi to capture images of the plants.
- Process the captured images using the Python script for ripeness detection.
- Display the processed image data and ripeness status on the web app.
4. Sensor Data Integration Test:
- Collect real-time data from all sensors (light [lux], soil moisture [200-2000], temperature [℉], humidity [%]).
- Verify that the ESP32 sends this data to the web app for visualization.
- Check the accuracy and stability of the displayed data.

Measurable Criteria:

I. The ESP32 should accurately control the grow lights based on light sensor data, maintaining optimal light levels for plant growth.

II. The water pump must activate when given the command to turn on from the ESP32.

III. The Raspberry Pi must successfully capture images and provide a ripeness assessment with an accuracy of at least 80%.

IV. The web app should display real-time sensor data (light, moisture, temperature, humidity) and image outputs without significant delay.

Score Sheet:

Test Case | Expected Outcome | Pass/Fail
Light Control | On/off function
Water Pump Activation | On/off function
Image Capture | Successful image capture
Ripeness Detection | Accurate ripeness assessment ( ≥ 80%)
Sensor Data Display | Real-time, accurate data on web app

Hardware Pinout

Component | ESP32 Pin # Raspberry Pi Pin # | Usage/Description
Soil Moisture Sensor | GPIO 34 | N/A | Moisture reading
— | GPIO 21 | N/A | Light level monitoring
— | GPIO 22 | N/A | Light level monitoring
Water Pump | GPIO 23 | N/A | Water pump control
Grow Lights | GPIO 24 | N/A | Grow lights control
Camera | N/A | USB | Image capture

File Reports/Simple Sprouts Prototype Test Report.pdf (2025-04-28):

## Boston University Electrical & Computer Engineering

EC 463 Senior Design Project

## First Prototype Report


by
Team 26

Dilhara DeSilva dilharad@bu.edu Arthur Hua ahua102@bu.edu
Alex Muntean munteana@bu.edu Jared Solis jared11@bu.edu Sourav Shib shib0826@bu.edu

Required Materials:

Hardware:
- ESP32 Microcontroller
- 12V DC Variable Power Supply
- Camera Module (Logi Webcam HD 1080p)
- 12V Peristaltic Water Pump
- Adafruit Soil Moisture Sensors (2)
- Temperature Sensor
- Humidity Sensor
- MOX Sensor (air quality)
- SRD (2)
- 9V Battery
- 11W Grow Light
- Inverter

Software:
- Python 3 Scripts
- Capturing photos
- Object recognition
- Arduino IDE
- React Native Expo
- Arduino IDE for ESP32
- Python scripts for image recognition (OpenCV, TensorFlow)
- Web server (Node.js) for data visualization
- Sensor handling libraries (Adafruit libraries for sensors)

Set Up:

The system consists of the following components:

1. ESP32: Manages sensor readings (soil moisture, temperature, humidity, MOX) and controls the water pump and grow lights using step recovery diodes.
2. Laptop: Handles image capture using the webcam and processes the images using a trained model for ripeness detection.
3. Power Supply: Uses a DC variable power supply for consistent voltage output due to unreliable battery performance in previous tests.
4. Web App: Displays scheduling information and all-time statistics (water, light).

Workflow Testing:
1. Light scheduled to turn on → ESP32 triggers grow light activation.
2. Soil moisture sensor detects dry soil → ESP32 triggers water pump activation.
a. Water pump scheduled to turn on → ESP32 triggers water pump activation.
3. Camera captures plant image → The laptop prompts the model → Model provides reasonable plant assessment → Web app displays scheduling information and all-time statistics.

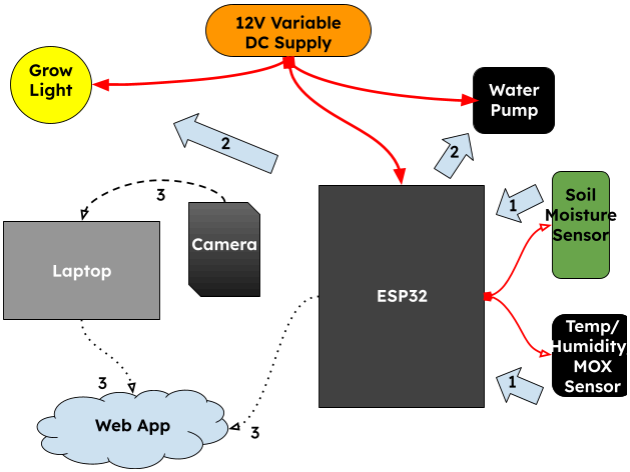
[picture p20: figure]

Figure 1: Illustration of Setup and Process Flow

Measurable Criteria:

I. The ESP32 should activate the grow lights when given the ON command, keeping light levels on and constant for plant growth.

II. The water pump must activate when given the command to turn on from the ESP32.

III. The camera and code script must successfully capture images and provide a reasonable plant assessment based on the image.

IV. The web app should display all-time information like total hours of light and total water deployed through scheduling without significant delay.

Score Sheet:

Test Case | Expected Outcome | Pass/Fail
Light Control | On/off function | ✓
Water Pump Activation | On/off function | ✓
Image Capture | Successful image capture | ✓
Plant Assessment | Plant type, plant health, ripeness | ✓
Sensor Data Display | Real-time, accurate data | ✓

Detailed Measurements:

Comprehensive testing was conducted to measure the performance of individual components and the overall system. The following measurements were recorded:

1. Soil Moisture Sensors:
- Sensor 1: Initial reading of 400 () before watering; post-watering, the reading increased to 1015, indicating optimal hydration.
- The sensor consistently provided accurate moisture levels, enabling reliable feedback for the water pump operation.
2. Temperature and Humidity Sensors:
- Temperature readings averaged 25°F, consistent with the controlled indoor environment.
- Humidity levels ranged between 20% and 40%, within the optimal range for the chosen plant type.
3. Air Quality Sensor (MOX):
- The MOX sensor measured CO₂ levels in ppm. During testing, CO₂ readings ranged from 350 ppm (ambient air quality) to 450 ppm, depending on environmental changes. These readings provide valuable data for understanding the growing environment.
4. Grow Lights:
- The grow lights were tested for simple on/off functionality. The lights activated reliably via the ESP32 command and remained operational for the desired duration. Total hours of light provided were tracked and displayed on the web app.
5. Water Pump:
- The water pump activated when manually triggered by the ESP32. It successfully delivered water until the soil moisture sensors indicated optimal levels. Total water dispensed was tracked and recorded on the web app.
6. Camera and Image Processing:
- Images captured by the camera were processed by the llama3.2vision model. Model responses included accurate identification of plant type, ripeness status, and health status, achieving an response time at approximately 4 minutes of processing per response.

Conclusions Based on Test Data:

The prototype testing revealed significant insights into the functionality and integration of the Simple Sprouts system. Key conclusions are as follows:

1. Grow Light and Water Pump Operation:
The ESP32 successfully controlled the on/off operation of both the grow lights and the water pump. While the grow lights and water pump performed reliably during manual testing, the lack of scheduling functionality highlighted an area for improvement. Scheduling automation is essential for reducing user intervention and improving the prototype's long-term reliability.
2. Sensor Data Integration:
The system seamlessly collected real-time data from all sensors, including soil moisture (2 sensors), temperature, humidity, and air quality (MOX sensor measuring CO₂ in ppm). These readings were accurately displayed on the web app, along with cumulative statistics such as total hours of grow light operation and total liters of water dispensed. The ability to monitor these metrics remotely demonstrates a critical step towards an autonomous vertical farming system.
3. Camera and Image Processing:
The camera model, integrated with chatbot functionality, provided accurate assessments of plant type, ripeness status, and health status. This feature adds significant value to the system by offering actionable insights to the user in an interactive format. While the reliance on a teammate's laptop for processing limits scalability, this temporary solution validated the potential of the image processing component.
4. Overall System Reliability:
The system proved reliable in its current state, with all sensors and actuators functioning as intended. However, addressing the lack of scheduling for the water pump and grow lights, as well as transitioning image processing to a dedicated onboard solution, are critical steps for the next iteration. These improvements will enhance autonomy and scalability for future deployments.

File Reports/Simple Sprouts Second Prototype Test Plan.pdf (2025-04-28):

## Boston University Electrical & Computer Engineering

EC 464 Senior Design Project

## Second Prototype Testing Plan


by
Team 26

Dilhara DeSilva dilharad@bu.edu Arthur Hua ahua102@bu.edu
Alex Muntean munteana@bu.edu Jared Solis jared11@bu.edu Sourav Shib shib0826@bu.edu

Required Materials

Hardware:
- Raspberry Pi 5
- 24V DC Power Supply
- 24V to 12V DC-DC Converter
- 12V to 5V DC-USB-C Output Converter
- Raspberry NoIR Camera Module
- 12V Peristaltic Water Pump
- 12V Solenoid Valves (2)
- Grow Light LED Strips (2)
- Soil Moisture Sensors (2)
- Temperature Sensor
- Humidity Sensor
- Air Quality Sensor
- 3 SRD Relays (Used to boost MOSFET current—one for the water pump, one for each LED strip)

Software:
- Python 3 Scripts (Raspberry Pi GPIO control, sensor handling, automation logic)
- Capturing Photos & Object Recognition (OpenCV, TensorFlow for plant analysis)
- React Native Expo (Mobile/Web UI for monitoring and control)
- Node.js Web Server (Data visualization and API communication)
- Adafruit Sensor Libraries (for data collection from environmental sensors)
- Firebase (Cloud-based data storage and real-time updates for system communication)

Modes of Operation:

1. Manual Mode: User manually controls watering and lighting via the web app.
2. Schedule Mode: User sets predefined schedules for watering and lighting cycles.

Set Up

The system consists of the following components:
- Raspberry Pi 5: Manages all sensor readings (soil moisture, temperature, humidity, and air quality), controls the water pump and grow lights via GPIO and SRD relays, and processes infrared images for plant health monitoring.

- Power Supply: Uses a 24V DC power supply with two DC-DC converters (12V for the water pump and solenoids, 5V for the Raspberry Pi).
- Web App: Displays real-time sensor data, images captured by the camera, and AI-based plant health assessments.
Note: The water level sensor is not used in this prototype due to wire length
limitations and the need for it to float.

Pre-testing Setup Procedure

1. Connect all sensors (soil moisture, temperature, humidity, air quality) to the Raspberry Pi and verify communication.
2. Ensure the Raspberry Pi is connected to the NoIR Camera and can capture infrared images using Python.
3. Verify optimal water levels in storage manually.
4. Set up the DC power supply to provide 12V power for the water circuit and 5V for the Raspberry Pi and grow lights.
5. Ensure proper relay control for the water pump and LED strips via the SRD relays.
6. Upload and run the control code on the Raspberry Pi for automation and monitoring.
7. Run a test script to ensure image capture and AI-based plant monitoring functions correctly.

Workflow Testing

1. Grow Light Activation → Raspberry Pi triggers grow lights via SRD relays based on the selected mode (Manual, or Schedule).
2. Watering System
- If soil moisture sensor detects dry soil → Raspberry Pi activates the water pump.
- The system alerts the user if water levels are low (manually checked in this prototype).
3. Camera & AI Processing
- Camera captures plant images in IR → Raspberry Pi processes plant health using AI.
- Web app displays sensor data, IR plant images, and AI-based assessments.

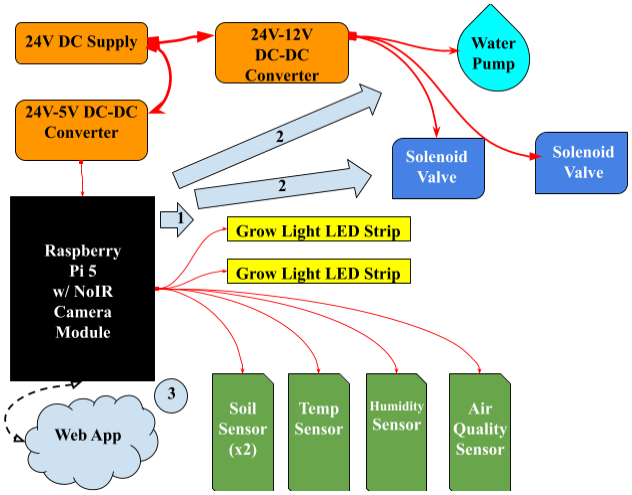
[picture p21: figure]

Figure 1: Illustration of Setup and Process Flow

Testing Procedure

Grow Light Test
- Verify that the Raspberry Pi triggers the grow lights via SRD relays according to the mode settings.
Water Pump & Soil Moisture Test
- Measure soil moisture levels using sensors.
- Ensure the water pump activates and stops at the desired moisture level.
- Validate the ON/OFF command functionality for the pump.
Camera & AI Image Processing Test
- Capture infrared images of the plants (lettuce, spinach, tomato) using the NoIR camera.
- Process captured images with AI to assess plant health and growth.
- Display real-time plant status on the web app.
Sensor Data Integration Test

- Collect real-time data from all sensors (soil moisture, temperature, humidity, air quality).
- Verify that the Raspberry Pi sends this data to Firebase and the web app.
- Check the accuracy and stability of displayed data.

Measurable Criteria

Test Case | Expected Outcome | Pass/Fail
Grow Light Control A. Scheduled mode B. Manual mode | Lights turn on/off as scheduled or in manual mode
Water Pump Activation A. Scheduled mode B. Manual mode | Pump activates at low moisture and stops when sufficient
Image Capture | Successful infrared image capture
AI Plant Assessment | Accurate AI evaluation of plant health
Sensor Data Display | Real-time, accurate data on web app and Firebase
Power Consumption | System operates efficiently

Future Plans & Notes

- Heater Implementation: The heater will be added in the final product but is not used in this prototype.
- PCB Integration: The second prototype does not use a custom PCB, but a PCB will be implemented in the final version for better efficiency and reliability.
- Historical Data Storage: The web app may store historical plant images and sensor data, but currently, only recent data is retained due to storage constraints.
- Improved GUI & AI Integration:
- The app will have a more intuitive interface.
- AI will provide recommendations for plant care based on image analysis.
- Sensor data visualization will be enhanced for better user experience.

Conclusion

The Simple Sprouts project integrates automated plant care with real-time monitoring, using Raspberry Pi-controlled sensors, relays, and AI-powered plant analysis. The system successfully incorporates manual and scheduled modes, providing flexibility based on plant needs. The cloud integration with Firebase allows seamless communication between components, ensuring efficient control and data storage.
The hardware implementation balances efficient power distribution, using a 24V DC supply stepped down to 12V and 5V for various components. The NoIR camera and AI model enhance the system by enabling plant health monitoring through infrared imaging, providing valuable insights into chlorophyll content and overall plant well-being.
While this prototype has validated key functionalities, future iterations will include a heater, PCB integration, and improved AI recommendations for plant care. With real-time data processing, image analysis, and an intuitive web-based control system, Simple Sprouts is a scalable solution for automated indoor gardening, offering a blend of technology and agriculture for sustainable growth.

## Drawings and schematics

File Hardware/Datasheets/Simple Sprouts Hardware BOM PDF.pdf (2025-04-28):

### Senior Design Expense Tracking

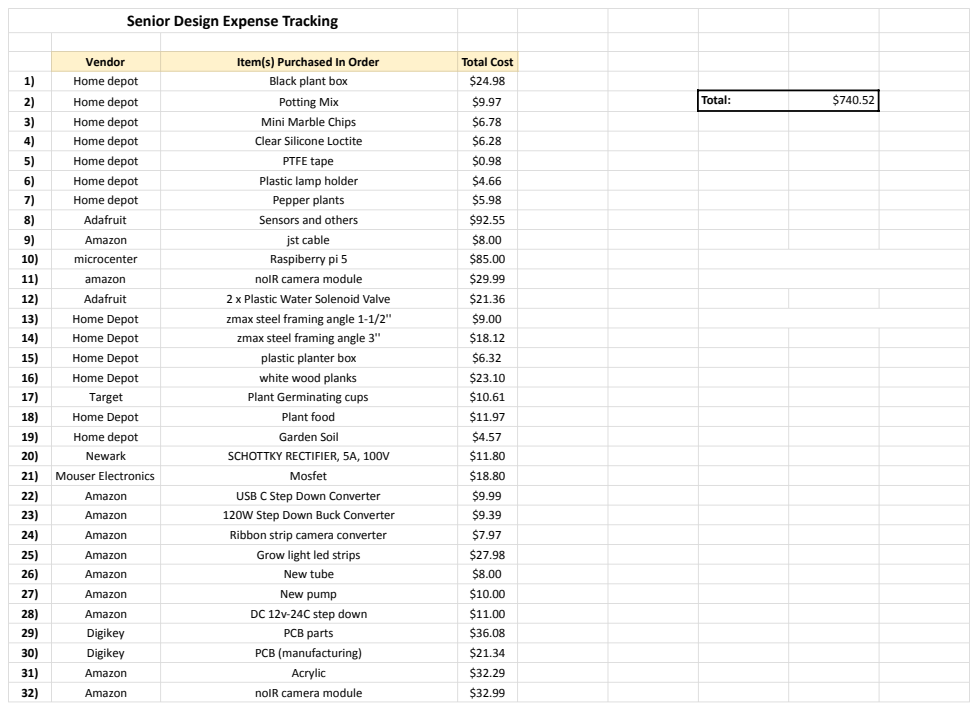
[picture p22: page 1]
Vendor; Item(s) Purchased In Order; Total Cost; Home depot; Black plant box; Potting Mix; Total:; Mini Marble Chips; Clear Silicone Loctite; PTFE tape; Plastic lamp holder; Pepper plants; Adafruit; Sensors and others; Amazon; jst cable; microcenter; Raspiberry pi 5; amazon; noIR camera module; 2 x Plastic Water Solenoid Valve; Home Depot; zmax steel framing angle 1-1/2''; zmax steel framing angle 3''; plastic planter box; white wood planks; Target; Plant Germinating cups; Plant food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

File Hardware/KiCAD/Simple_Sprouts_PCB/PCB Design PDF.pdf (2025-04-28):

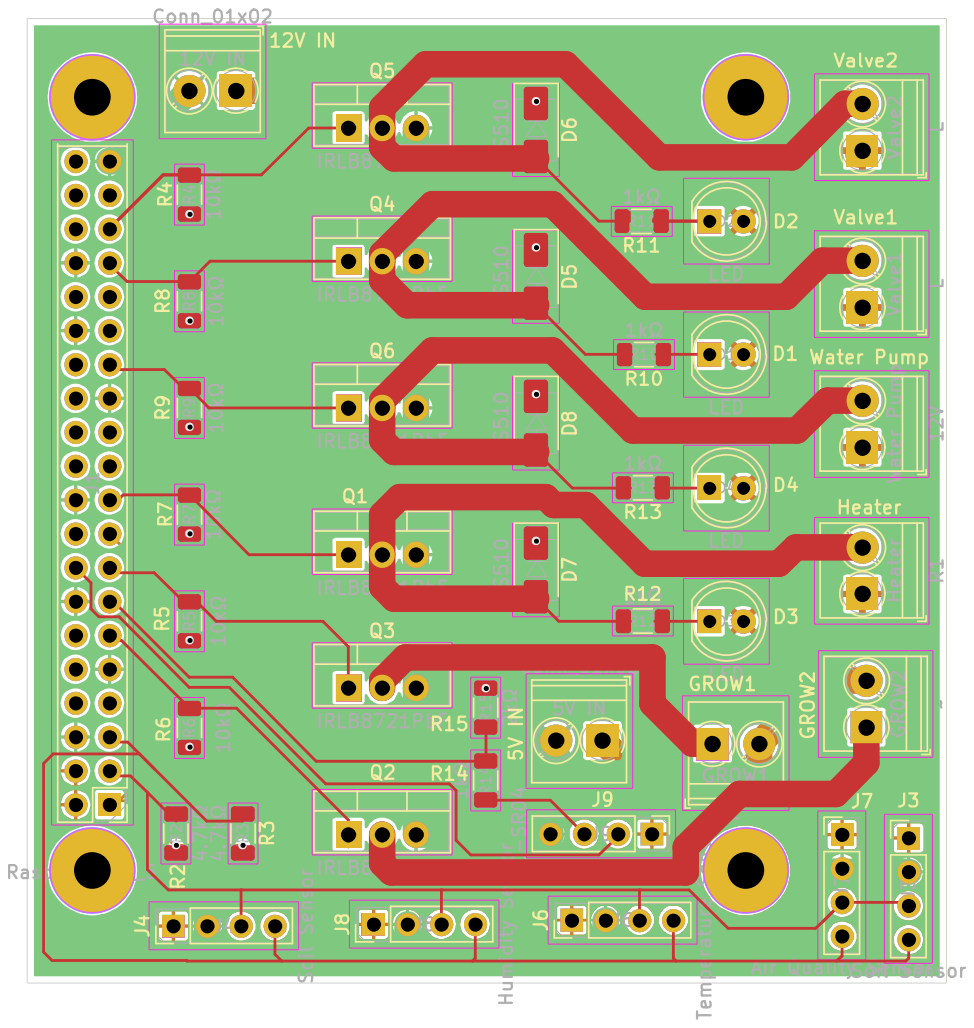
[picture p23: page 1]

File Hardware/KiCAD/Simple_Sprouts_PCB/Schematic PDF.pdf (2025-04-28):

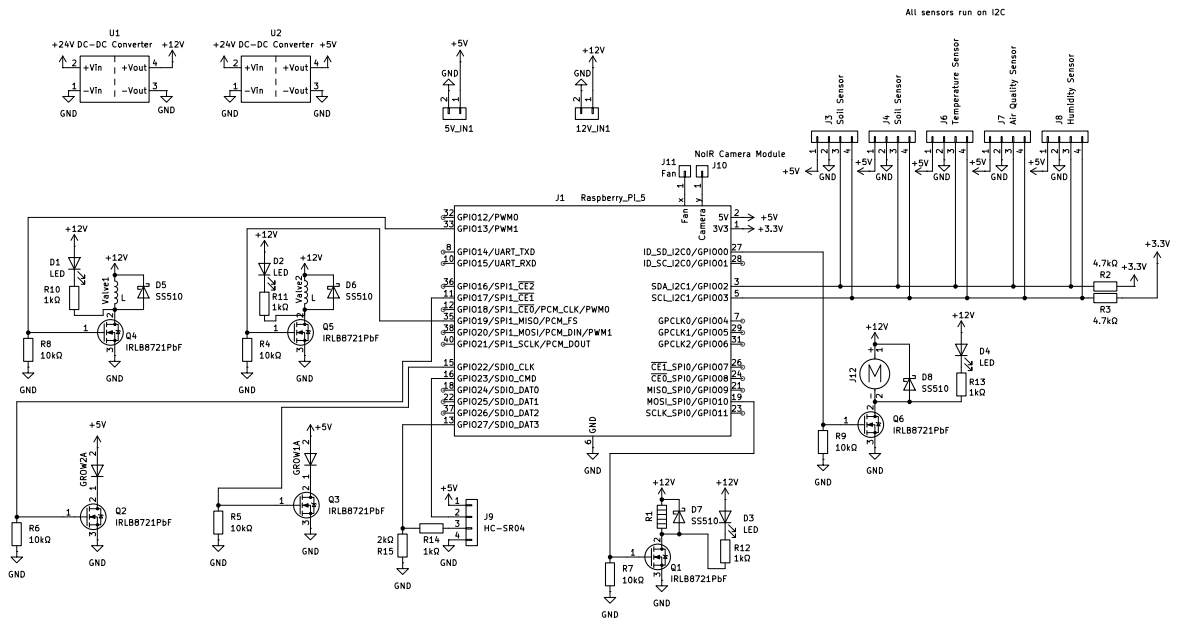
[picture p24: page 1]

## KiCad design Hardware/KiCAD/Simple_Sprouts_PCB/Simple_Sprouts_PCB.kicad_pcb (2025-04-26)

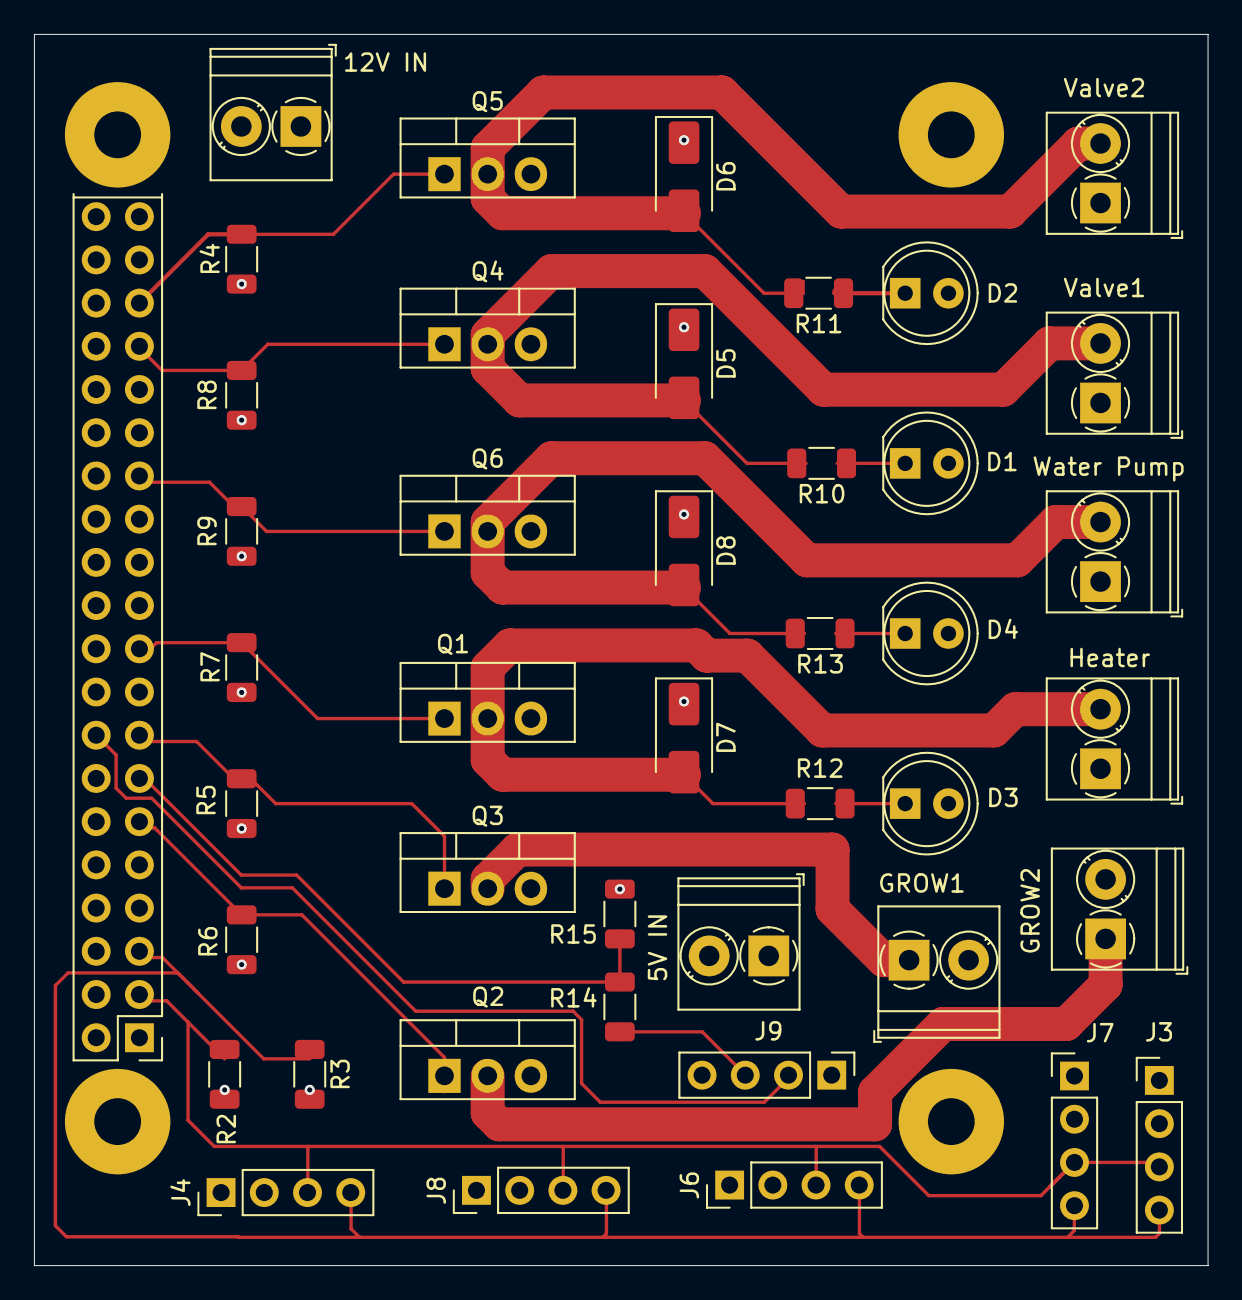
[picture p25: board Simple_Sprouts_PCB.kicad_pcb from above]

Board: 4 copper layers, 69.0 x 72.4 mm, 43 parts (0 on the bottom side), 25 nets.

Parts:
5V IN, 12V IN: Conn_01x02; TerminalBlock_Phoenix_PT-1,5-2-3.5-H_1x02_P3.50mm_Horizontal
D1, D2, D3, D4: LED; LED_D5.0mm
D5, D6, D7, D8: SS510; D_SMA
GROW1, GROW2: TerminalBlock_Phoenix_PT-1,5-2-3.5-H_1x02_P3.50mm_Horizontal
Heater: R1; TerminalBlock_Phoenix_PT-1,5-2-3.5-H_1x02_P3.50mm_Horizontal
J1: Raspberry_Pi_5; RPI Correct
J3, J4: Soil Sensor; PinHeader_1x04_P2.54mm_Vertical
J6: Temperature Sensor; PinHeader_1x04_P2.54mm_Vertical
J7: Air Quality Sensor; PinHeader_1x04_P2.54mm_Vertical
J8: Humidity Sensor; PinHeader_1x04_P2.54mm_Vertical
J9: HC-SR04; PinHeader_1x04_P2.54mm_Vertical
Q1, Q2, Q3, Q4, Q5, Q6: IRLB8721PbF; TO-220-3_Vertical
R2, R3: 4.7kΩ; R_1206_3216Metric
R4, R5, R6, R7, R8, R9: 10kΩ; R_1206_3216Metric
R10, R11, R12, R13, R14: 1kΩ; R_1206_3216Metric
R15: 2kΩ; R_1206_3216Metric
Valve1, Valve2: L; TerminalBlock_Phoenix_PT-1,5-2-3.5-H_1x02_P3.50mm_Horizontal
Water Pump: 12V; TerminalBlock_Phoenix_PT-1,5-2-3.5-H_1x02_P3.50mm_Horizontal

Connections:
+3.3V: J1.1 (3V3), J1.17 (3V3), R2.1, R3.2
+5V: 5V IN.1, GROW1.2, GROW2.2, J1.2 (5V), J1.4 (5V), J3.1, J4.1, J6.1, J7.1, J8.1, J9.1
+12V: 12V IN.1, D1.2 (A), D2.2 (A), D3.2 (A), D4.2 (A), D5.1 (K), D6.1 (K), D7.1 (K), D8.1 (K), Heater.1, Valve1.1, Valve2.1, Water Pump.1 (+)
GND: 5V IN.2, 12V IN.2, J1.6 (GND), J1.9 (GND), J1.14 (GND), J1.20 (GND), J1.25 (GND), J1.30 (GND), J1.34 (GND), J1.39 (GND), J3.2, J4.2, J6.2, J7.2, J8.2, J9.4, Q1.3 (S), Q2.3 (S), Q3.3 (S), Q4.3 (S), Q5.3 (S), Q6.3 (S), R4.2, R5.2, R6.2, R7.2, R8.2, R9.2, R15.2
unnamed: D1.1 (K), R10.1
unnamed: D2.1 (K), R11.1
unnamed: D3.1 (K), R12.1
unnamed: D4.1 (K), R13.1
unnamed: D5.2 (A), Q4.2 (D), R10.2, Valve1.2
unnamed: D6.2 (A), Q5.2 (D), R11.2, Valve2.2
unnamed: D7.2 (A), Heater.2, Q1.2 (D), R12.2
unnamed: D8.2 (A), Q6.2 (D), R13.2, Water Pump.2 (-)
unnamed: J1.33 (GPIO13/PWM1), Q4.1 (G), R8.1
unnamed: J1.11 (GPIO17/SPI1_~CE1), Q2.1 (G), R6.1
unnamed: J1.35 (GPIO19/SPI1_MISO/PCM_FS), Q5.1 (G), R4.1
unnamed: J1.15 (GPIO22/SDIO_CLK), Q3.1 (G), R5.1
unnamed: J1.16 (GPIO23/SDIO_CMD), J9.2
unnamed: J1.13 (GPIO27/SDIO_DAT3), R14.1, R15.1
unnamed: J1.27 (ID_SD_I2C0/GPIO00), Q6.1 (G), R9.1
unnamed: J1.19 (MOSI_SPI0/GPIO10), Q1.1 (G), R7.1
unnamed: J1.5 (SCL_I2C1/GPIO03), J3.4, J4.4, J6.4, J7.4, J8.4, R3.1
unnamed: J1.3 (SDA_I2C1/GPIO02), J3.3, J4.3, J6.3, J7.3, J8.3, R2.2
unnamed: J9.3, R14.2
unnamed: GROW2.1, Q2.2 (D)
unnamed: GROW1.1, Q3.2 (D)

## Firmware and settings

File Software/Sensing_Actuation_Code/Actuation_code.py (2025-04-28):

import time
import gpiod
import firebase_admin
from firebase_admin import credentials, db
from gpiozero import DistanceSensor  # Import the DistanceSensor from gpiozero

# --- GPIO Pin Definitions ---
BOTTOM_LIGHT_PIN = 22  # bottom light
TOP_LIGHT_PIN = 17     # top light
BOTTOM_VALVE_PIN = 13  # bottom water valve
TOP_VALVE_PIN = 19     # top water valve
PUMP_PIN = 0           # shared water pump
HEATER_PIN = 10        # heater

'''
Alternative Pin Set (commented out)
BOTTOM_LIGHT_PIN = 21
TOP_LIGHT_PIN = 20
BOTTOM_VALVE_PIN = 16
TOP_VALVE_PIN = 12
PUMP_PIN = 1
HEATER_PIN = 25
'''

# --- Initialize GPIO Chip and Lines ---
chip = gpiod.Chip('gpiochip0')
bottom_light_line = chip.get_line(BOTTOM_LIGHT_PIN)
top_light_line = chip.get_line(TOP_LIGHT_PIN)
bottom_valve_line = chip.get_line(BOTTOM_VALVE_PIN)
top_valve_line = chip.get_line(TOP_VALVE_PIN)
pump_line = chip.get_line(PUMP_PIN)
heater_line = chip.get_line(HEATER_PIN)

# Request lines for output
bottom_light_line.request(consumer="BOTTOM_LIGHT", type=gpiod.LINE_REQ_DIR_OUT)
top_light_line.request(consumer="TOP_LIGHT", type=gpiod.LINE_REQ_DIR_OUT)
bottom_valve_line.request(consumer="BOTTOM_VALVE", type=gpiod.LINE_REQ_DIR_OUT)
top_valve_line.request(consumer="TOP_VALVE", type=gpiod.LINE_REQ_DIR_OUT)
pump_line.request(consumer="PUMP", type=gpiod.LINE_REQ_DIR_OUT)
heater_line.request(consumer="HEATER", type=gpiod.LINE_REQ_DIR_OUT)

# --- Initialize Firebase ---
cred = credentials.Certificate("/home/pi/final_testing/sensor_firebase_key.json")
firebase_admin.initialize_app(cred, {
    'databaseURL': 'https://simple-sprouts-database-default-rtdb.firebaseio.com/'
})
ref = db.reference("flags_test")
sensor_readings_ref = db.reference("sensor_readings/latest")

# --- Initialize Ultrasonic Sensor ---
ultrasonic_sensor = DistanceSensor(echo=27, trigger=23, max_distance=4)
next_ultrasonic_sample = time.monotonic()

# --- Component State Dictionary ---
components = {
    "bottom_light": {
        "gpio": bottom_light_line,
        "state": False,
        "on_duration": 0,
        "off_duration": 0,
        "next_toggle": time.monotonic(),
        "init_key": "bottom_initialized",
        "mode_key": "bottom_mode",
        "edit_flag": "bottom_mode_light_edit"
    },
    "top_light": {
        "gpio": top_light_line,
        "state": False,
        "on_duration": 0,
        "off_duration": 0,
        "next_toggle": time.monotonic(),
        "init_key": "top_initialized",
        "mode_key": "top_mode",
        "edit_flag": "top_mode_light_edit"
    },
    "bottom_water": {
        "gpio": (bottom_valve_line, pump_line),
        "state": False,
        "on_duration": 0,
        "off_duration": 0,
        "next_toggle": time.monotonic(),
        "init_key": "bottom_initialized",
        "mode_key": "bottom_mode",
        "edit_flag": "bottom_mode_water_edit"
    },
    "top_water": {
        "gpio": (top_valve_line, pump_line),
        "state": False,
        "on_duration": 0,
        "off_duration": 0,
        "next_toggle": time.monotonic(),
        "init_key": "top_initialized",
        "mode_key": "top_mode",
        "edit_flag": "top_mode_water_edit"
    }
}

# Heater state
heater_state = False

# --- Helper Functions ---

def update_schedule(comp_name, data, current_time):
    comp = components[comp_name]
    if comp_name in ["bottom_light", "top_light"]:
        total_on = data.get(f"{comp_name}_ref_on_hrs", 0) * 1 + data.get(f"{comp_name}_ref_on_mins", 0) * 1
        total_off = data.get(f"{comp_name}_ref_off_hrs", 0) * 1 + data.get(f"{comp_name}_ref_off_mins", 0) * 1
        comp["on_duration"] = total_on
        comp["off_duration"] = total_off
    elif comp_name in ["bottom_water", "top_water"]:
        amount = data.get(f"{comp_name}_amount", 0)
        total_off = (data.get(f"{comp_name}_ref_days", 0) * 1 +
                     data.get(f"{comp_name}_ref_hrs", 0) * 1 +
                     data.get(f"{comp_name}_ref_mins", 0) * 1)
        comp["on_duration"] = amount
        comp["off_duration"] = total_off
    if comp["next_toggle"] < current_time:
        if comp["state"]:
            comp["next_toggle"] = current_time + comp["on_duration"]
        else:
            comp["next_toggle"] = current_time + comp["off_duration"]

def update_adaptive_schedule(comp_name, data, current_time):
    comp = components[comp_name]
    if comp_name == "bottom_light":
        total_on = data.get("adp_bottom_light_on_hrs", 0) * 1
        total_off = data.get("adp_bottom_light_off_hrs", 0) * 1
    elif comp_name == "top_light":
        total_on = data.get("adp_top_light_on_hrs", 0) * 1
        total_off = data.get("adp_top_light_off_hrs", 0) * 1
    comp["on_duration"] = total_on
    comp["off_duration"] = total_off
    if comp["next_toggle"] < current_time:
        if comp["state"]:
            comp["next_toggle"] = current_time + comp["on_duration"]
        else:
            comp["next_toggle"] = current_time + comp["off_duration"]

def set_valve(comp, value):
    if isinstance(comp["gpio"], tuple):
        comp["gpio"][0].set_value(1 if value else 0)
    else:
        comp["gpio"].set_value(1 if value else 0)

def adaptive_water_logic(comp_name, sensor_value, current_time):
    comp = components[comp_name]
    if "watering_until" not in comp:
        comp["watering_until"] = 0
    if sensor_value < 450:
        comp["state"] = True
        comp["watering_until"] = current_time + 5
    elif sensor_value < 680:
        if comp["state"]:
            comp["watering_until"] = current_time + 5
    else:
        comp["state"] = False
        comp["watering_until"] = 0

def handle_manual_mode(data):
    if data.get("bottom_initialized", False):
        if data.get("bottom_mode", "manual") == "manual":
            bottom_light_line.set_value(1 if data.get("bottom_man_light", False) else 0)
            bottom_valve_line.set_value(1 if data.get("bottom_man_water", False) else 0)
    if data.get("top_initialized", False):
        if data.get("top_mode", "manual") == "manual":
            top_light_line.set_value(1 if data.get("top_man_light", False) else 0)
            top_valve_line.set_value(1 if data.get("top_man_water", False) else 0)

def update_pump(data):
    bottom_mode = data.get("bottom_mode", "manual")
    if bottom_mode in ["scheduling", "adaptive"]:
        bottom_state = components["bottom_water"]["state"]
    else:
        bottom_state = data.get("bottom_man_water", False)
    top_mode = data.get("top_mode", "manual")
    if top_mode in ["scheduling", "adaptive"]:
        top_state = components["top_water"]["state"]
    else:
        top_state = data.get("top_man_water", False)
    pump_state = bottom_state or top_state
    pump_line.set_value(1 if pump_state else 0)

def update_heater(data, sensors):
    global heater_state
    current_temp = sensors.get("temp", 20)
    target_temp = data.get("target_temp", 25)
    if not heater_state and current_temp < (target_temp - 5):
        heater_state = True
    elif heater_state and current_temp >= target_temp:
        heater_state = False
    heater_line.set_value(1 if heater_state else 0)

# --- Main Event Loop ---
while True:
    current_time = time.monotonic()
    
    # Ultrasonic sampling
    if current_time >= next_ultrasonic_sample:
        distance_cm = ultrasonic_sensor.distance * 100
        sensor_readings_ref.update({"ultrasonic": distance_cm})
        next_ultrasonic_sample = current_time + 5

    data = ref.get()

    # Bottom light processing
    comp = components["bottom_light"]
    mode = data.get(comp["mode_key"], "manual")
    if data.get(comp["init_key"], False):
        if mode == "scheduling":
            if data.get(comp["edit_flag"], False):
                update_schedule("bottom_light", data, current_time)
                ref.update({comp["edit_flag"]: False})
            if current_time >= comp["next_toggle"]:
                comp["state"] = not comp["state"]
                comp["gpio"].set_value(1 if comp["state"] else 0)
                comp["next_toggle"] = current_time + (comp["on_duration"] if comp["state"] else comp["off_duration"])
        elif mode == "adaptive":
            if data.get("adp_bottom_light_edit", False):
                update_adaptive_schedule("bottom_light", data, current_time)
                ref.update({"adp_bottom_light_edit": False})
            if current_time >= comp["next_toggle"]:
                comp["state"] = not comp["state"]
                comp["gpio"].set_value(1 if comp["state"] else 0)
                comp["next_toggle"] = current_time + (comp["on_duration"] if comp["state"] else comp["off_duration"])

    # Top light processing
    comp = components["top_light"]
    mode = data.get(comp["mode_key"], "manual")
    if data.get(comp["init_key"], False):
        if mode == "scheduling":
            if data.get(comp["edit_flag"], False):
                update_schedule("top_light", data, current_time)
                ref.update({comp["edit_flag"]: False})
            if current_time >= comp["next_toggle"]:
                comp["state"] = not comp["state"]
                comp["gpio"].set_value(1 if comp["state"] else 0)
                comp["next_toggle"] = current_time + (comp["on_duration"] if comp["state"] else comp["off_duration"])
        elif mode == "adaptive":
            if data.get("adp_top_light_edit", False):
                update_adaptive_schedule("top_light", data, current_time)
                ref.update({"adp_top_light_edit": False})
            if current_time >= comp["next_toggle"]:
                comp["state"] = not comp["state"]
                comp["gpio"].set_value(1 if comp["state"] else 0)
                comp["next_toggle"] = current_time + (comp["on_duration"] if comp["state"] else comp["off_duration"])

    # Bottom water processing
    comp = components["bottom_water"]
    mode = data.get(comp["mode_key"], "manual")
    if data.get(comp["init_key"], False):
        if mode == "scheduling":
            if data.get(comp["edit_flag"], False):
                update_schedule("bottom_water", data, current_time)
                ref.update({comp["edit_flag"]: False})
            if current_time >= comp["next_toggle"]:
                comp["state"] = not comp["state"]
                set_valve(comp, comp["state"])
                comp["next_toggle"] = current_time + (comp["on_duration"] if comp["state"] else comp["off_duration"])
        elif mode == "adaptive":
            sensors = db.reference("Sensors").get()
            soil_value = sensors.get("soil_2", 700)
            adaptive_water_logic("bottom_water", soil_value, current_time)
            set_valve(comp, comp["state"])

    # Top water processing
    comp = components["top_water"]
    mode = data.get(comp["mode_key"], "manual")
    if data.get(comp["init_key"], False):
        if mode == "scheduling":
            if data.get(comp["edit_flag"], False):
                update_schedule("top_water", data, current_time)
                ref.update({comp["edit_flag"]: False})
            if current_time >= comp["next_toggle"]:
                comp["state"] = not comp["state"]
                set_valve(comp, comp["state"])
                comp["next_toggle"] = current_time + (comp["on_duration"] if comp["state"] else comp["off_duration"])
        elif mode == "adaptive":
            sensors = db.reference("Sensors").get()
            soil_value = sensors.get("soil_1", 700)
            adaptive_water_logic("top_water", soil_value, current_time)
            set_valve(comp, comp["state"])

    # Manual mode override
    handle_manual_mode(data)

    # Update pump
    update_pump(data)

    # Update heater
    sensors = db.reference("Sensors").get()
    update_heater(data, sensors)

    time.sleep(0.5)

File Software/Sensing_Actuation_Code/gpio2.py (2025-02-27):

import gpiod
import time

# Define GPIO pins
LED_PIN_17 = 17  # GPIO 17
LED_PIN_27 = 27  # GPIO 27
LED_PIN_22 = 22  # GPIO 22
LED_PIN_10 = 10  # GPIO 10
LED_PIN_9 = 9    # GPIO 9

# Use the correct GPIO chip (Check with ls /dev/gpiochip*)
chip = gpiod.Chip('gpiochip0')  # Change this if needed

# Get the GPIO lines for LEDs
led_line_17 = chip.get_line(LED_PIN_17)
led_line_27 = chip.get_line(LED_PIN_27)
led_line_22 = chip.get_line(LED_PIN_22)
led_line_10 = chip.get_line(LED_PIN_10)
led_line_9 = chip.get_line(LED_PIN_9)

# Request exclusive access to the lines and configure them as outputs
led_line_17.request(consumer="LED_17", type=gpiod.LINE_REQ_DIR_OUT)
led_line_27.request(consumer="LED_27", type=gpiod.LINE_REQ_DIR_OUT)
led_line_22.request(consumer="LED_22", type=gpiod.LINE_REQ_DIR_OUT)
led_line_10.request(consumer="LED_10", type=gpiod.LINE_REQ_DIR_OUT)
led_line_9.request(consumer="LED_9", type=gpiod.LINE_REQ_DIR_OUT)

print("Commands:")
print(" '1'   -> Turn ON LED 17")
print(" '0'   -> Turn OFF LED 17")
print(" '11'  -> Turn ON LED 27")
print(" '00'  -> Turn OFF LED 27")
print(" '111' -> Turn ON LED 22")
print(" '000' -> Turn OFF LED 22")
print(" '1111' -> Turn ON LED 10")
print(" '0000' -> Turn OFF LED 10")
print(" '11111' -> Turn ON LED 9")
print(" '00000' -> Turn OFF LED 9")
print("Type 'exit' to quit.")

try:
    while True:
        user_input = input("Enter command (1/0/11/00/111/000/1111/0000/11111/00000): ").strip()  # Get user input
        
        if user_input == "1":
            led_line_17.set_value(1)
            print("LED 17 ON")
        elif user_input == "0":
            led_line_17.set_value(0)
            print("LED 17 OFF")
        elif user_input == "11":
            led_line_27.set_value(1)
            print("LED 27 ON")
        elif user_input == "00":
            led_line_27.set_value(0)
            print("LED 27 OFF")
        elif user_input == "111":
            led_line_22.set_value(1)
            print("LED 22 ON")
        elif user_input == "000":
            led_line_22.set_value(0)
            print("LED 22 OFF")
        elif user_input == "1111":
            led_line_10.set_value(1)
            print("LED 10 ON")
        elif user_input == "0000":
            led_line_10.set_value(0)
            print("LED 10 OFF")
        elif user_input == "11111":
            led_line_9.set_value(1)
            print("LED 9 ON")
        elif user_input == "00000":
            led_line_9.set_value(0)
            print("LED 9 OFF")
        elif user_input.lower() == "exit":
            break  # Exit the loop if user types 'exit'
        else:
            print("Invalid input! Use '1', '0', '11', '00', '111', '000', '1111', '0000', '11111', '00000', or 'exit'.")

finally:
    # Release the GPIO lines and clean up resources on program exit
    led_line_17.release()
    led_line_27.release()
    led_line_22.release()
    led_line_10.release()
    led_line_9.release()
    chip.close()
    print("GPIO released. Exiting...")

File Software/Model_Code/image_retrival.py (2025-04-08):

import requests
import base64
import time
import moondream as md
from PIL import Image
from dotenv import load_dotenv
import os

load_dotenv()  # Load environment variables from .env
Api_key = os.getenv("API_KEY")

model = md.vl(api_key= "")

# Firebase URL pointing to the "Image_in_base64" field (include .json)
FIREBASE_URL_image = "https://simple-sprouts-database-default-rtdb.firebaseio.com/pages/more_info/plant_info/image.json"
FIREBASE_URL_Response = "https://simple-sprouts-database-default-rtdb.firebaseio.com/pages/more_info/plant_info/health_status_desc.json"
FIREBASE_URL_chat_flag = "https://simple-sprouts-database-default-rtdb.firebaseio.com/pages/more_info/plant_info/health_status_query.json"
# FIREBASE_URL_Init_curpage= "https://simple-sprouts-database-default-rtdb.firebaseio.com/pages/initialization/current_page.json"
FIREBASE_URL_Plant_query = "https://simple-sprouts-database-default-rtdb.firebaseio.com/pages/initialization/plant_valid_query.json"
FIREBASE_URL_Plant_valid="https://simple-sprouts-database-default-rtdb.firebaseio.com/pages/initialization/plant_valid.json"
FIREBASE_URL_Plant_name="https://simple-sprouts-database-default-rtdb.firebaseio.com/Plants.json"
# FIREBASE_URL_More_info_curpage= "https://simple-sprouts-database-default-rtdb.firebaseio.com/pages/more_info/current_page.json"
# FIREBASE_URL_More_info_plant_info_curpage="https://simple-sprouts-database-default-rtdb.firebaseio.com/pages/more_info/plant_info/current_page.json"

FIREBASE_URL_query_LLM="https://simple-sprouts-database-default-rtdb.firebaseio.com/llm.json"
FIREBASE_URL_query_LLM_flag="https://simple-sprouts-database-default-rtdb.firebaseio.com/llm/query_flag.json"
FIREBASE_URL_query_LLM_response="https://simple-sprouts-database-default-rtdb.firebaseio.com/llm/response.json"
FIREBASE_URL_health_report="https://simple-sprouts-database-default-rtdb.firebaseio.com/health_report.json"
FIREBASE_URL_Plant_stage_top="https://simple-sprouts-database-default-rtdb.firebaseio.com/Plant_stages/Top.json"
FIREBASE_URL_Plant_stage_bottom="https://simple-sprouts-database-default-rtdb.firebaseio.com/Plant_stages/Bottom.json"
FIREBASE_URL_User_query="https://simple-sprouts-database-default-rtdb.firebaseio.com/User_query.json"


# Path to save the retrieved image
OUTPUT0_ORIGINAL_PATH = "original_0.png"
OUTPUT0_CLRMAPPED_PATH = "color_mapped_image_0.png"
OUTPUT1_ORIGINAL_PATH = "original_1.png"
OUTPUT1_CLRMAPPED_PATH = "color_mapped_image_1.png"

def retrieve_image_from_firebase():
    # Fetch the base64 image data from Firebase
    response = requests.get(FIREBASE_URL_image)
    if response.status_code == 200:
        image_data = response.json()  # Retrieve the base64 string
        if image_data:
            # Decode the base64 string and save it as an image file
            with open(OUTPUT_ORIGINAL_PATH, "wb") as image_file:
                image_file.write(base64.b64decode(image_data['Image_in_base64_original']))
            print(f"Image successfully retrieved and saved as {OUTPUT_ORIGINAL_PATH}")
            with open(OUTPUT_CLRMAPPED_PATH, "wb") as image_file:
                image_file.write(base64.b64decode(image_data['Image_in_base64_color_mapped']))
            print(f"Image successfully retrieved and saved as {OUTPUT_CLRMAPPED_PATH}")
        else:
            print("No image data found in the response.")
    else:
        print(f"Failed to retrieve image. HTTP Status Code: {response.status_code}")

def upload_to_firebase(data: dict,image) -> None:
        if image==1:
            response = requests.put(FIREBASE_URL_image, json=data)
        if image==2:
            response = requests.put(FIREBASE_URL_Response, json=data)
        if image==3:
            response = requests.put(FIREBASE_URL_chat_flag, json=data)
        if image==4:
            response = requests.put(FIREBASE_URL_Plant_query, json=data)
        if image==5:
            response = requests.put(FIREBASE_URL_Plant_valid, json=data)
        if image==6:
            response = requests.put(FIREBASE_URL_query_LLM, json=data)
        if image==7:
            response = requests.put(FIREBASE_URL_query_LLM_response, json=data)
        if image==8:
            response = requests.put(FIREBASE_URL_health_report, json=data)
        if image==9:
            response = requests.put(FIREBASE_URL_Plant_stage_top, json=data)
        if image==10:
            response = requests.put(FIREBASE_URL_Plant_stage_bottom, json=data)
        print(f"Firebase response: {response.text}")
        response.close()

# Run the function
# retrieve_image_from_firebase()

while True:
    getModel = requests.get(FIREBASE_URL_chat_flag)
    # getPlantQuery =requests.get(FIREBASE_URL_Plant_query)
    # getPlntvalid =requests.get(FIREBASE_URL_Plant_valid)
    # getPltname =requests.get(FIREBASE_URL_Plant_name)
    # run_Pltname = getPltname.json()
    getQueryLLM =requests.get(FIREBASE_URL_query_LLM)
    # getUserQuery =requests.get(FIREBASE_URL_User_query)
    # run_UserQuery=getUserQuery.json()


    if getModel.status_code==200:
        # run_Model = getModel.json()
        # run_PlantQuery = getPlantQuery.json()
        # run_Plntvalid = getPlntvalid.json()
        run_QueryLLM=getQueryLLM.json()

        print(run_Pltname)
        # retrieve_image_from_firebase()
        image = Image.open(OUTPUT0_ORIGINAL_PATH)
        encoded_image = model.encode_image(image)

        if run_QueryLLM['query_flag']:
            #0-1 is asking if the plant can be planted indoors, 2-3 asks if the plant is healthy,
            #4-5 asks how many hours of growlight does the plant need, 6-7 asks about the stages of each plant,
            #8-9 ask about harvest time, 10-11 allow user to directly prompt the model.

            if run_QueryLLM['cmd_id']==0: #bottom layer
                getPltname =requests.get(FIREBASE_URL_Plant_name)
                run_Pltname = getPltname.json()
                answer_plant_indoors = model.query(encoded_image, f"Ignore the image, Can {run_Pltname['Bottom']} be planted indoor enviroment with growlights?")["answer"]
                print("Answer:", answer_plant_indoors)
                data={"response":answer_plant_indoors, "query_flag": False, "cmd_id":0}
                upload_to_firebase(data,6)
                # data={"query_flag": False}
                # upload_to_firebase(data,6)

            if run_QueryLLM['cmd_id']==1: #bottom layer
                getPltname =requests.get(FIREBASE_URL_Plant_name)
                run_Pltname = getPltname.json()
                answer_plant_indoors = model.query(encoded_image, f"Ignore the image, Can {run_Pltname['Top']} be planted indoor enviroment with growlights?")["answer"]
                print("Answer:", answer_plant_indoors)
                data={"response":answer_plant_indoors, "query_flag": False, "cmd_id":0}
                upload_to_firebase(data,6)
                # data={"query_flag": False}
                # upload_to_firebase(data,6)
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

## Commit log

2024-11-07 Temp & Light & Humidity Sensor
2024-11-15 Added water pump code
2024-11-15 Water Pump code
2024-11-19 Create sensors_test_1.ino
    first version for sensor code
2024-11-19 Create pin_control.ino
    This is the initial test code to trigger the pins that activate the pump and lights
2024-11-19 Create esp32_sensors_firebase_prototype.ino
    Working prototype code for the sensors and database
2024-11-21 Create timer_test_code.ino
    testing timer code by reading from firebase
2025-02-13 Create sensing_code.py
    Testing the raspberry code
2025-02-26 Create led_firebase.py
    New script for the gpio control using timers and values from firebase
2025-02-27 Create ultrasonic.py
    code for ultrasonic
2025-02-27 new camera code
2025-04-08 fixes issue camera code crashes
    [Camera_noIr.py, image_retrival.py]
2025-04-26 Reorganizing files
    [Good_bom.csv, Simple_Sprouts_PCB.kicad_pcb, Simple_Sprouts_PCB.kicad_sch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]
2025-04-27 fix software folder organization
    [Actuation_code.py, firebase_sensor.py, gpio.py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]
2025-04-28 commit
    datasheet upload and file organization
    [Simple_Sprouts_PCB.kicad_pcb, Simple_Sprouts_PCB.kicad_sch, bom.csv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]
2025-04-28 Update README_HARDWARE.md
    power requirements table
2025-04-28 commit
    photos folder + bom insertion
    [BOM.csv]
2025-04-28 Added CAD Files
    Added step files of our CAD drawings
    [Assembly 1.step, Drip Tray.step, Floor.step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]
2025-04-28 bom
    BOM
    [BOM.csv, Simple Sprouts Hardware BOM.xlsx]
